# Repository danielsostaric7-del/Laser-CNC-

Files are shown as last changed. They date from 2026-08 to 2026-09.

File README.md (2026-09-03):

# 100 mm XY Laser CNC

I designed and built this small laser CNC engraver around two 100 mm linear stages and a LaserTree 5 W module. The frame, laser-height adjustment, and electronics enclosure were modeled in SOLIDWORKS. A Wemos D1 R32 running FluidNC controls the two axis through a CNC Shield V3 and DRV8825 drivers.

<p align="center">
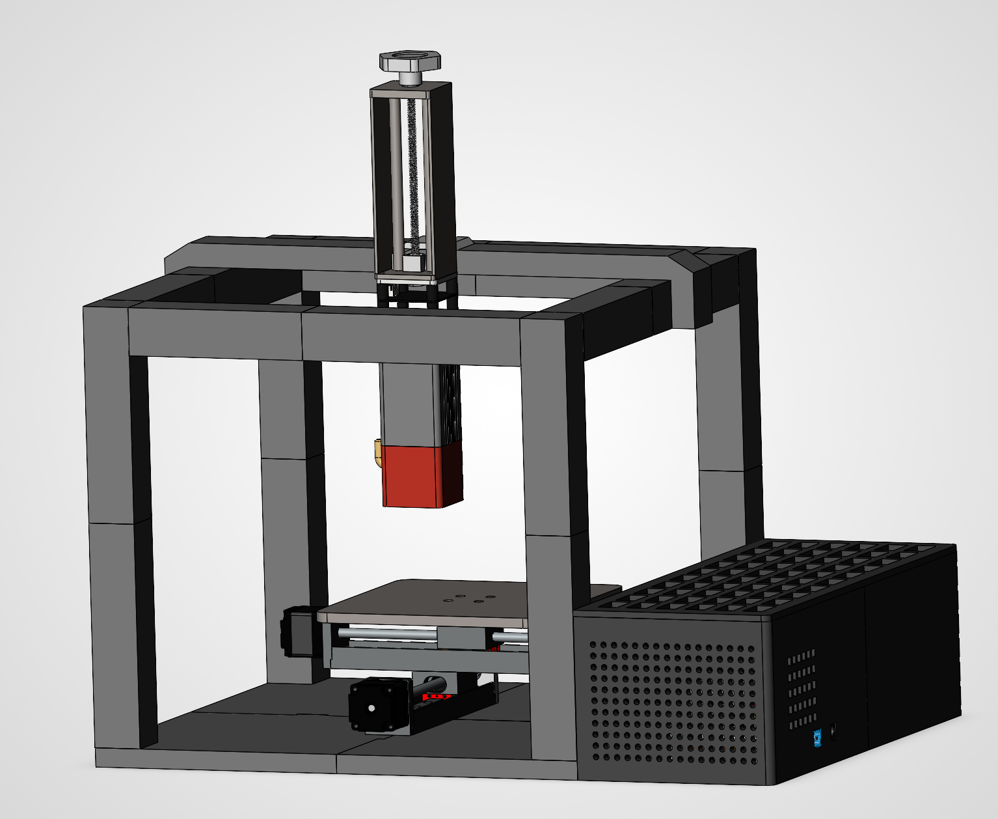
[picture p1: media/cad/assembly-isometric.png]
Full CNC assembly — my SOLIDWORKS isometric screenshot
  
</p>

[See all five SOLIDWORKS views](docs/cad-gallery.md)

## The finished machine

| Front | Electronics Box |
| --- | --- |
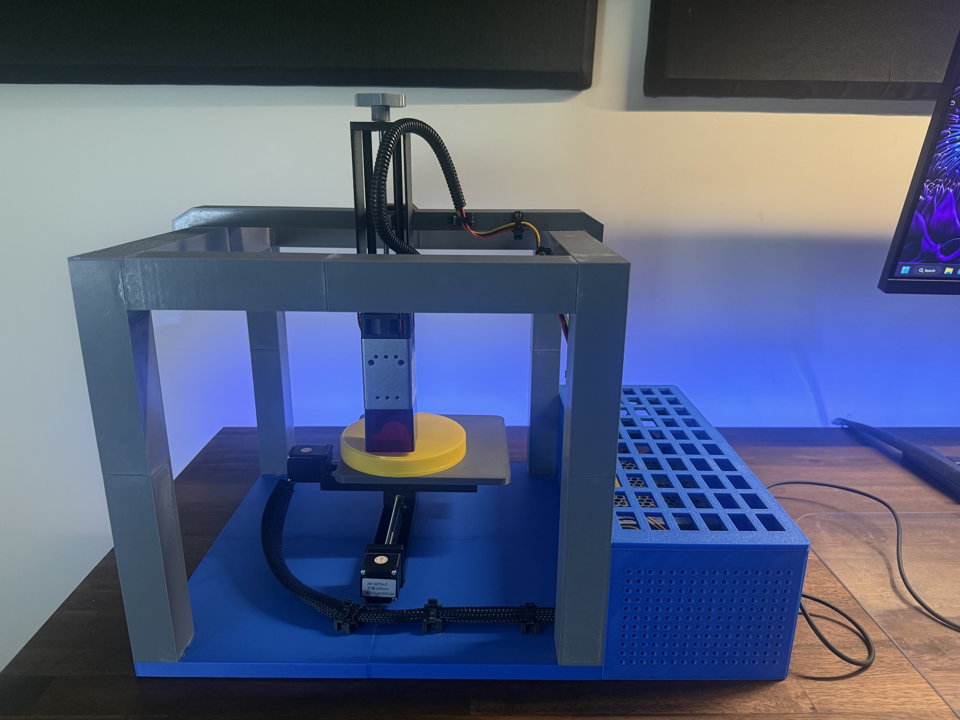
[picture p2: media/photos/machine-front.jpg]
Front of the finished CNC
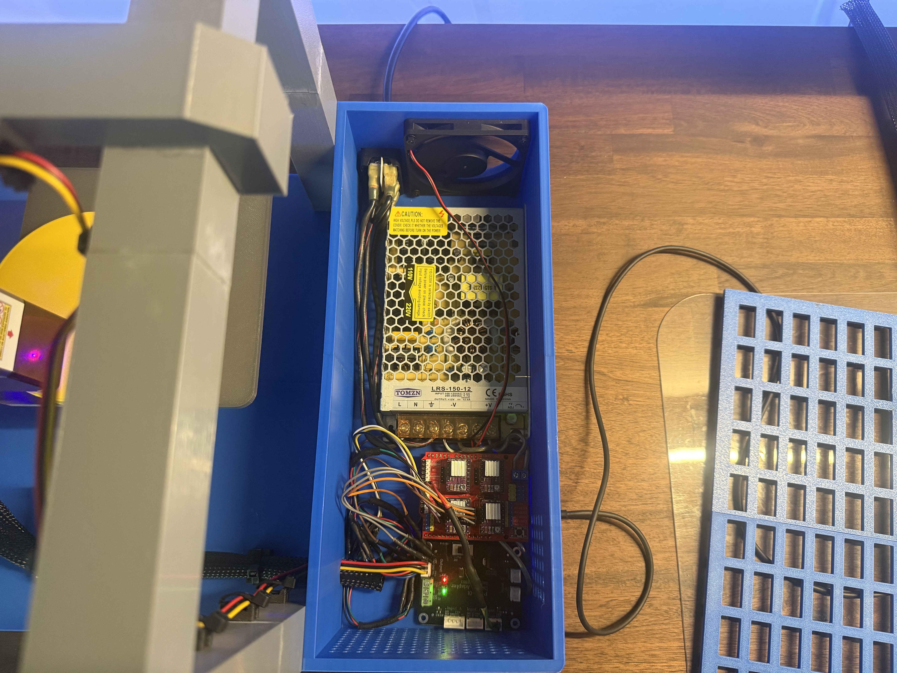
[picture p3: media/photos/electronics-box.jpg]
Electronics box of the finished CNC
|  |  |

[See all six photos](docs/photos.md), including the laser mount, electronics, power inlet, and test piece.

[Download the video](https://github.com/danielsostaric7-del/100mm-xy-laser-cnc/raw/refs/heads/main/media/video/assembly-overview.mp4) · [Video notes](docs/video.md)

## Setup

- 100 mm travel on each axis
- 3,200 steps/mm with 1/32 microstepping
- 600 mm/min configured maximum travel rate
- FluidNC v4 on a Wemos D1 R32
- 5 kHz laser PWM on GPIO19

The full pinout and motion settings are in [config.yaml](firmware/config.yaml).

## Circuit diagram

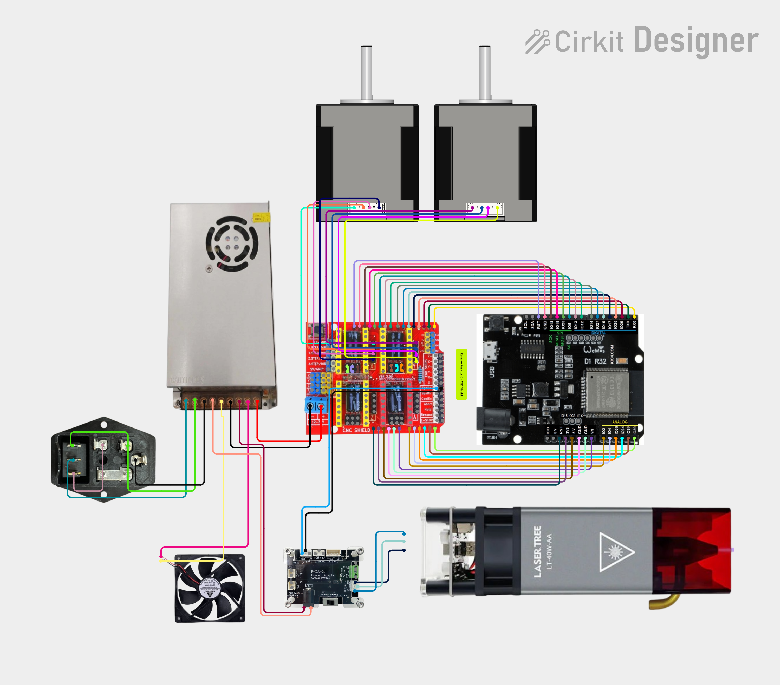
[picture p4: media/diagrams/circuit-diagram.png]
CNC wiring and circuit diagram


Click the diagram to open it at full size.

## Project files

| File or folder | What's inside |
| --- | --- |
| [CNC Assembly.SLDASM](cad/CNC%20Assembly.SLDASM) | The complete machine assembly |
| [CAD folder](cad/) | SOLIDWORKS parts and subassemblies |
| [FluidNC configuration](firmware/config.yaml) | Pin assignments and machine settings |
| [Circuit diagram](docs/circuit-diagram.md) | Wiring layout |
| [Bill of Material](docs/BOM.md) | Main parts and purchase links |

Keep the CAD folders together when opening the main assembly so SOLIDWORKS can find the referenced parts.

## Safety

This machine uses a high-power laser and electricity. The open frame shown here is not a laser-safe enclosure. Use a suitable enclosure, emergency stop, ventilation, and laser eyewear rated for the wavelength. Check grounding, polarity, driver current limits, and the laser's off-state before running it. Never leave it operating unattended.

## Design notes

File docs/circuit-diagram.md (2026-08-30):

# Circuit diagram

The wiring layout for the CNC controller, motors, laser, and power supply.

CNC wiring and circuit diagram

Click the diagram to open it at full size. Pin assignments and machine settings are in the [FluidNC configuration](../firmware/config.yaml).

[Bill of Material](BOM.md) · [Back to the project](../README.md)

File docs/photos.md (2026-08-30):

# Photos

The finished machine, a closer look at the hardware, and a test piece.

| Front | Side |
| --- | --- |
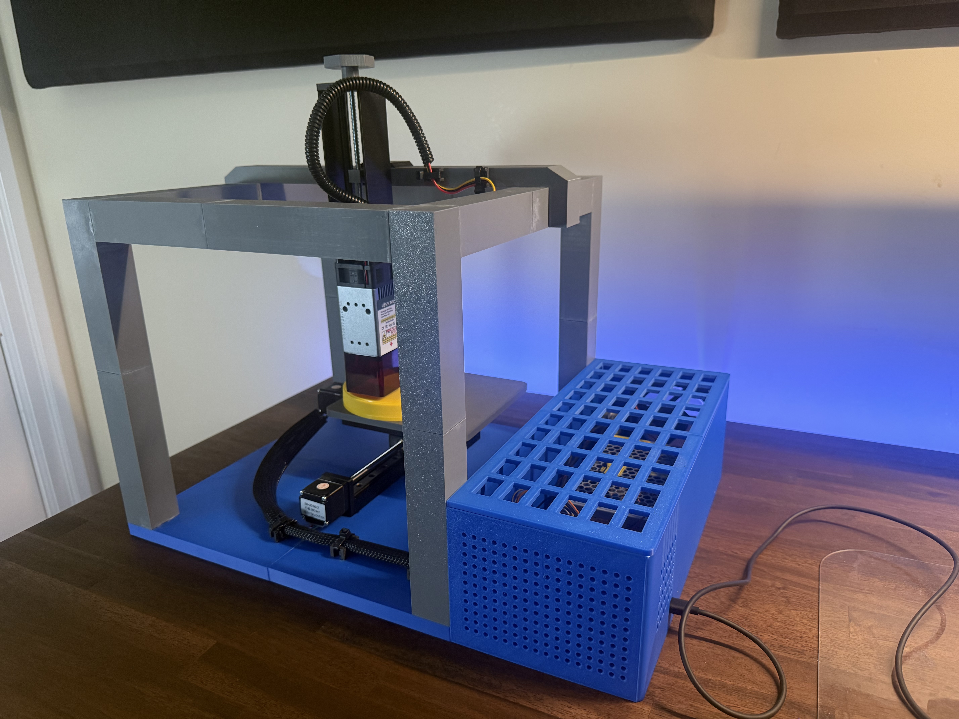
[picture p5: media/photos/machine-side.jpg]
Side of the completed CNC
| Front of the completed CNC |  |

| Laser mount and height adjustment | Inside the electronics enclosure |
| --- | --- |
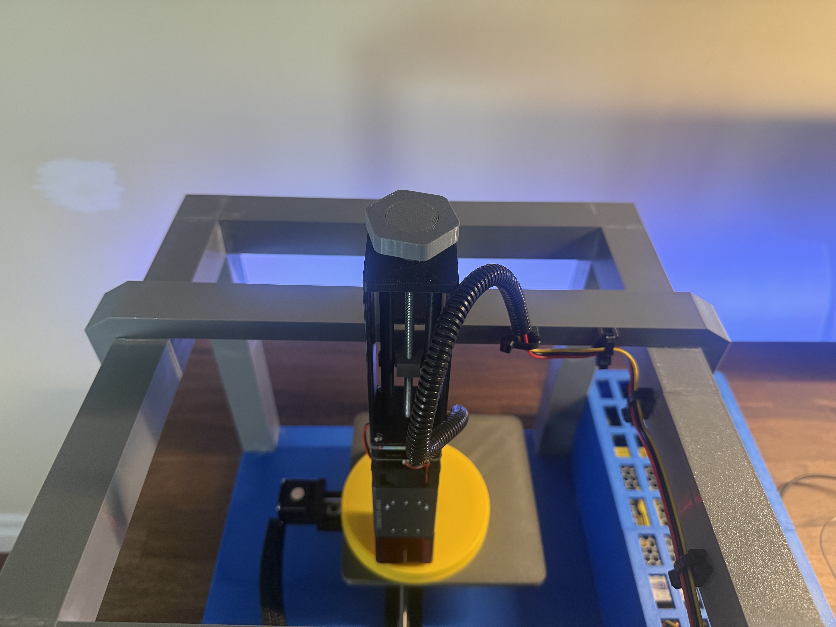
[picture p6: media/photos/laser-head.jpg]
Laser mount and height adjustment
|  | Power supply, controller, and wiring |

| Power inlet and cooling fan | Test piece |
| --- | --- |
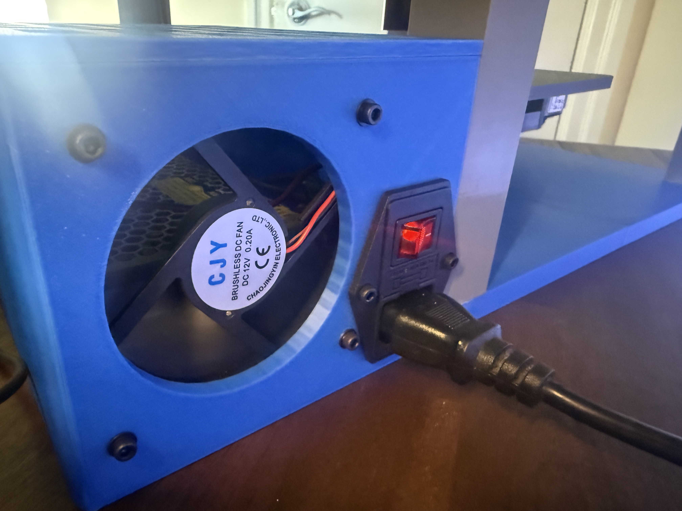
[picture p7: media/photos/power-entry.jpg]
Power inlet, switch, and fan
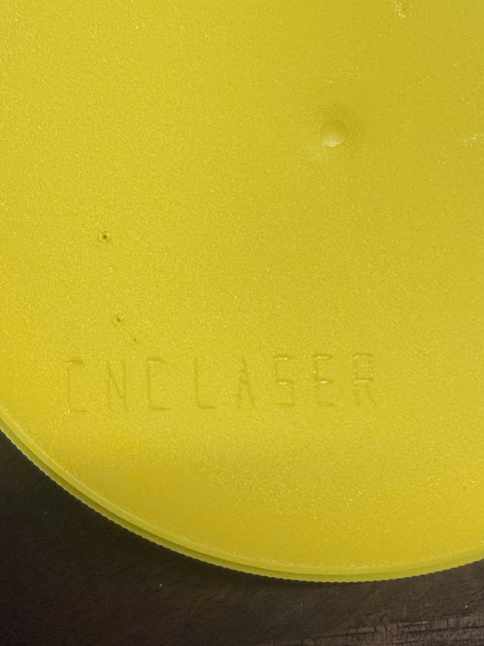
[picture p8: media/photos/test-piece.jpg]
Close-up of the test piece
|  |  |

Click a photo to view it at full size.

[SOLIDWORKS screenshots](cad-gallery.md) · [Circuit diagram](circuit-diagram.md) · [Back to the project](../README.md)

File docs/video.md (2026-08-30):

# Video

A short clip of the CNC.

[Download assembly-overview.mp4](https://github.com/danielsostaric7-del/100mm-xy-laser-cnc/raw/refs/heads/main/media/video/assembly-overview.mp4)

Use this download link instead of GitHub's file preview, which may say the video is too large to display. Open the downloaded MP4 in your video player. 

[Photos](photos.md) · [SOLIDWORKS screenshots](cad-gallery.md) · [Back to the project](../README.md)

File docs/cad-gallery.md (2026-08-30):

# SOLIDWORKS screenshots

Five views of the full CNC assembly, captured directly in SOLIDWORKS.

## Isometric

Full CNC assembly, isometric view

| Front | Side |
| --- | --- |
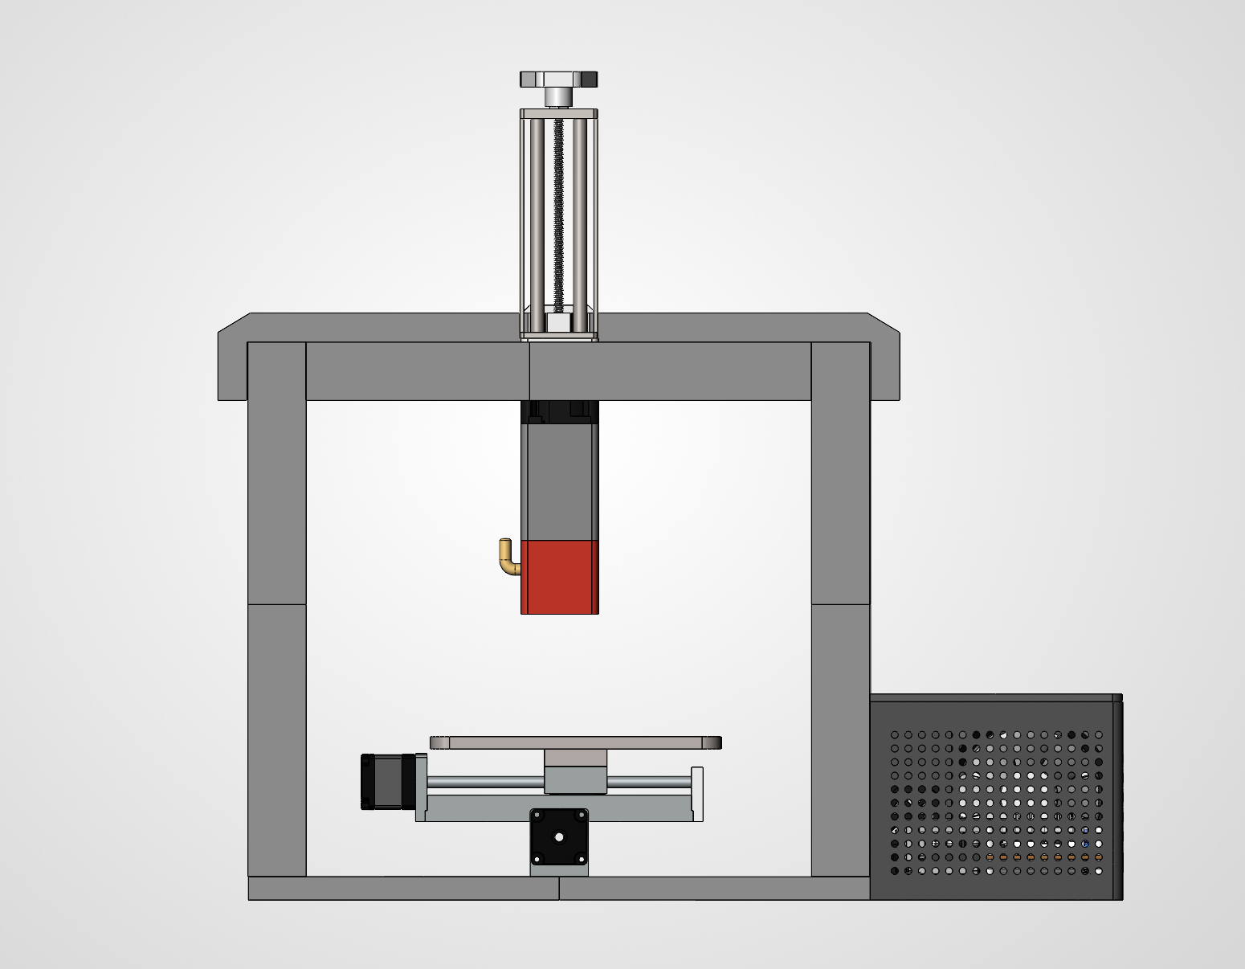
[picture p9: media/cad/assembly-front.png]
Front view
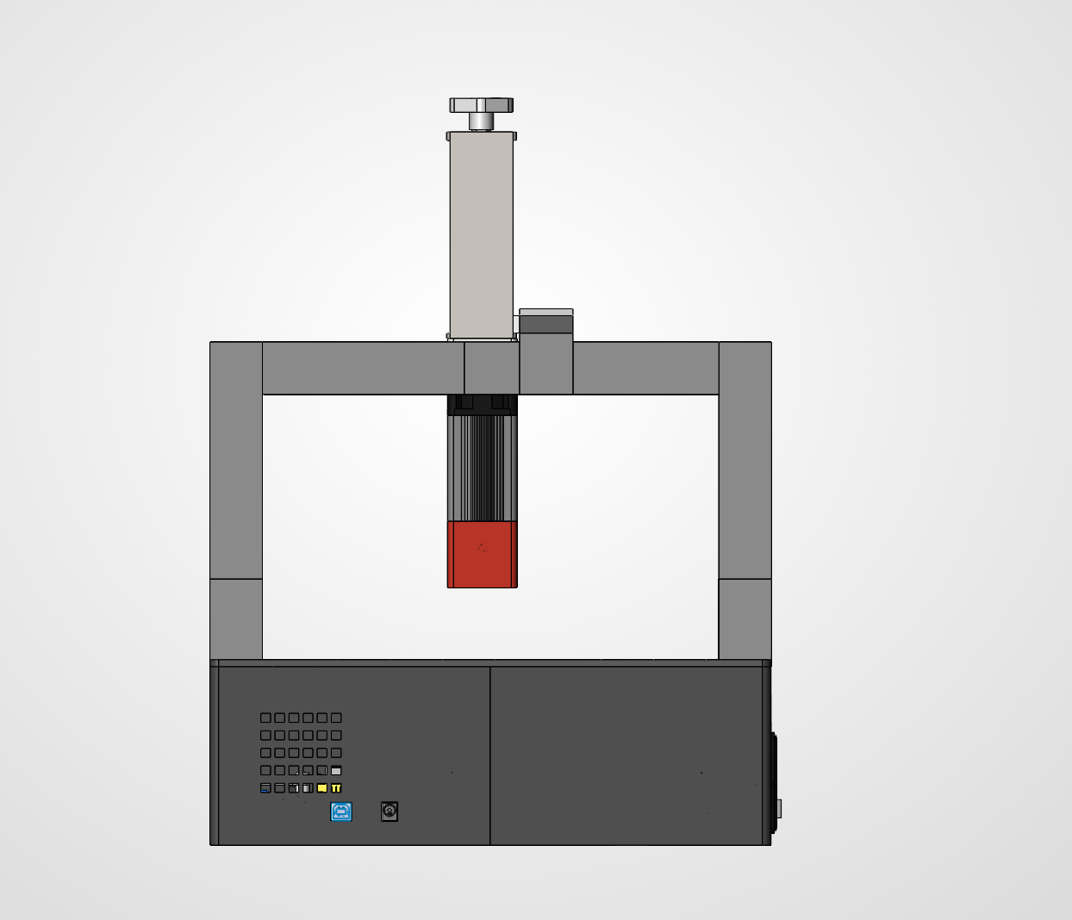
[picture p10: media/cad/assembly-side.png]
Side view
|  |  |

| Back | Top |
| --- | --- |
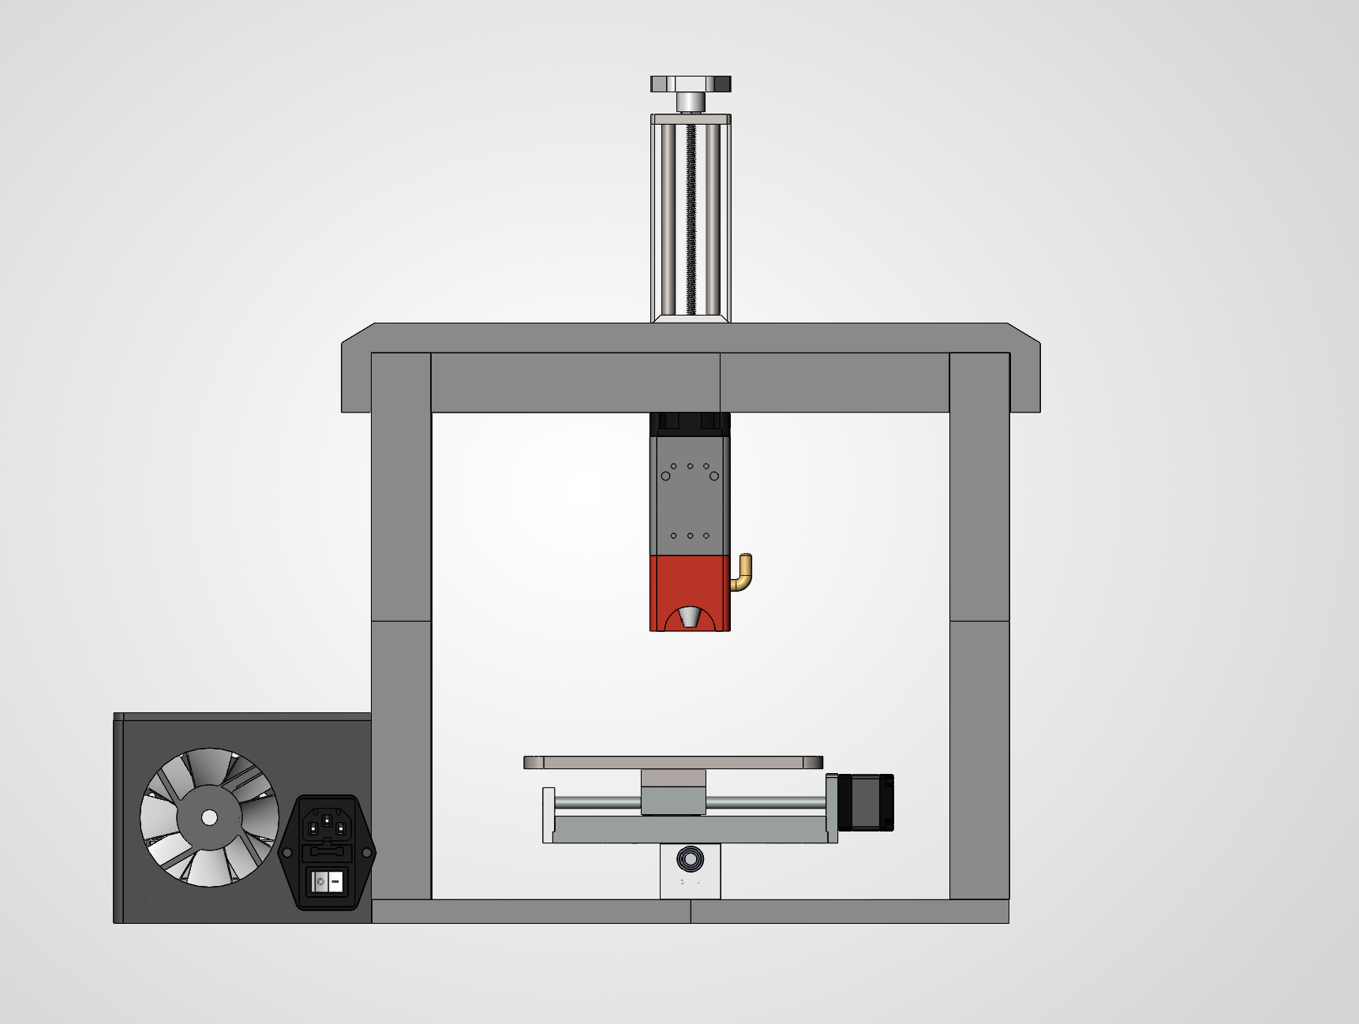
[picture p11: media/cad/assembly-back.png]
Back view
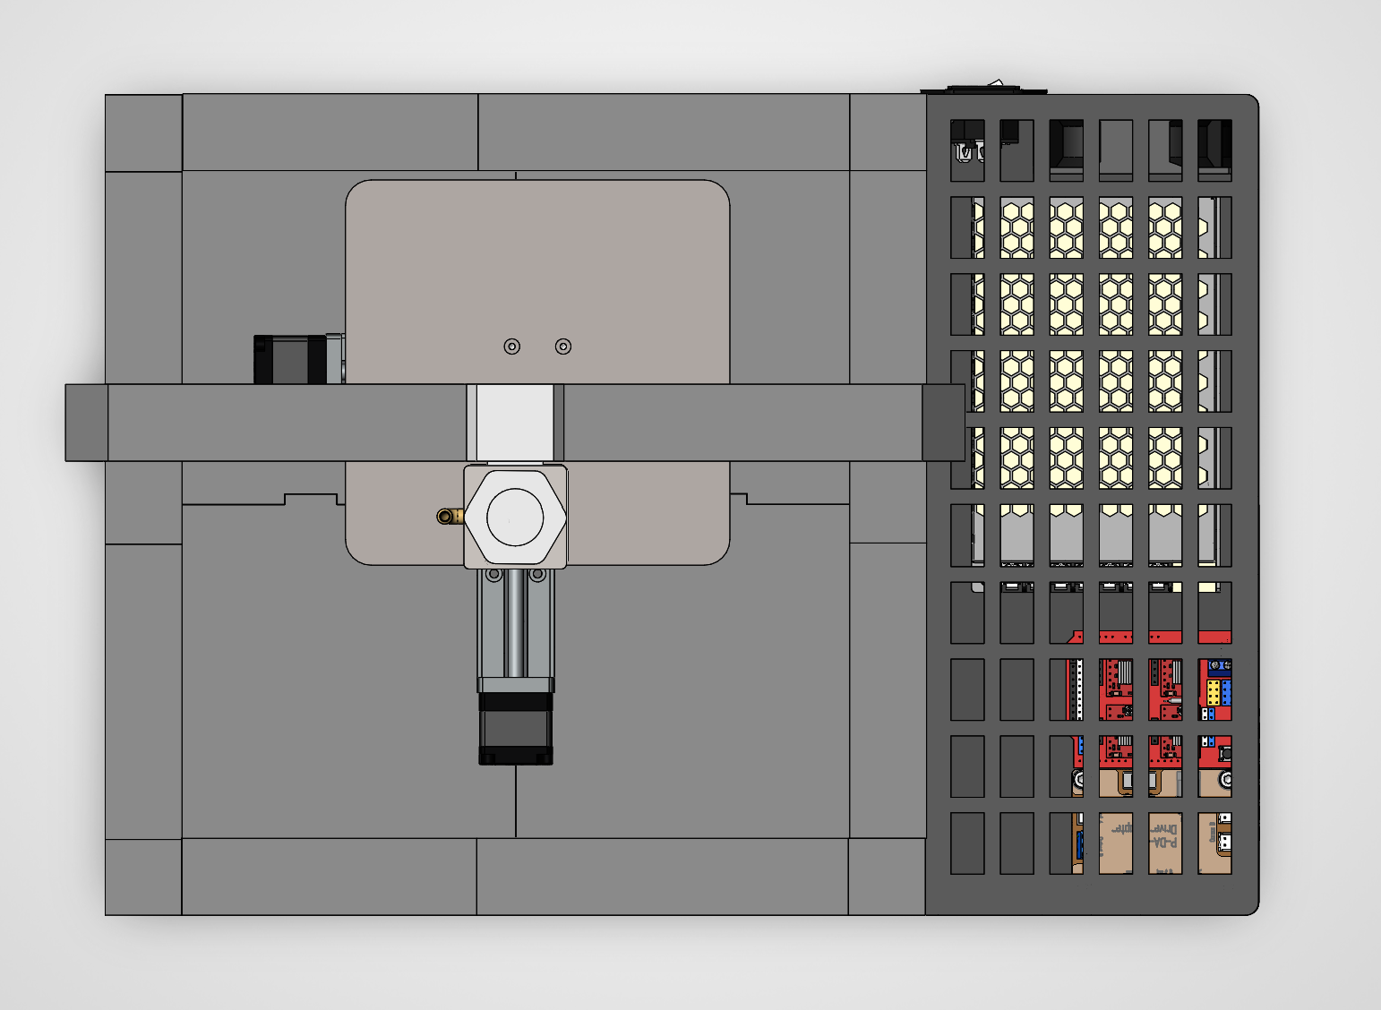
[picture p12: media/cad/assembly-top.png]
Top view
|  |  |

Click a screenshot to view it at full size.

[Open the assembly file](../cad/CNC%20Assembly.SLDASM) · [See the finished machine](photos.md) · [Back to the project](../README.md)

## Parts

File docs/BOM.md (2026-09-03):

# Bill of Material

The main parts used in this build.

| Part | Quantity |
| --- | ---: |
| Wemos D1 R32 | 1 |
| CNC Shield V3 | 1 |
| DRV8825 stepper driver | 2 |
| NEMA 11 linear stage, 100 mm travel | 2 |
| LaserTree LT-40W-A laser module, 5 W optical output | 1 |
| P-DA-01 laser driver adapter | 1 |
| LRS-150-12 power supply, 12 V / 150 W | 1 |
| IEC320-C14 inlet and switch | 1 |
| 12 V cooling fan | 1 |
| Custom frame, laser mount, and electronics enclosure | 1 set |

## Purchase links

These are the AliExpress listings from my orders. Check the selected size and version before ordering; some pages offer several options.

| Part | Link |
| --- | --- |
| Wemos D1 R32 | [AliExpress](https://www.aliexpress.com/item/32910354223.html) |
| Cooling fan | [AliExpress](https://www.aliexpress.com/item/1005007144892529.html) |
| CNC Shield V3 and stepper drivers | [AliExpress](https://www.aliexpress.com/item/1005006478108991.html) |
| LaserTree laser module | [AliExpress](https://www.aliexpress.com/item/1005006031010342.html) |
| Electrical Power Socket | [AliExpress](https://www.aliexpress.com/item/1005003012523694.html) |
| Linear Rail Motor | [AliExpress](https://www.aliexpress.com/item/1005008513205849.html) |
| Power supply | [AliExpress](https://www.aliexpress.com/item/1005008638665400.html) |

[Circuit diagram](circuit-diagram.md) · [Back to the project](../README.md)

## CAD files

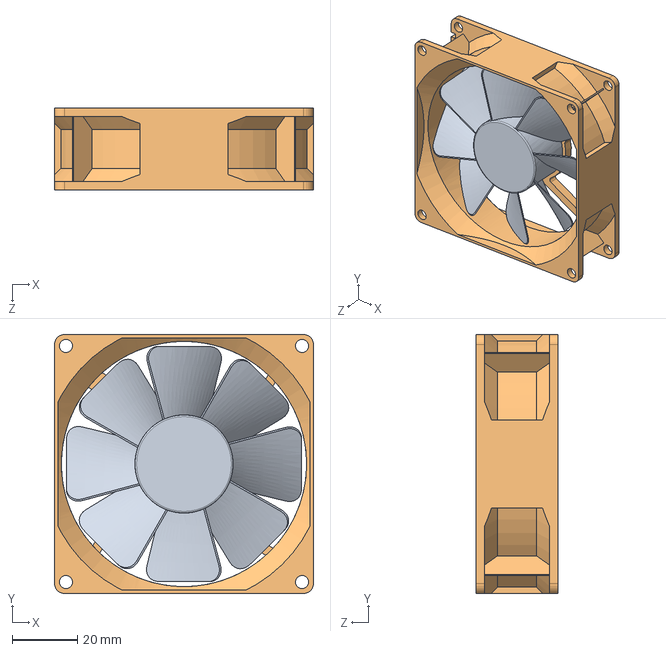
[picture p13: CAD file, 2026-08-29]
cad/Fan/cooler.SLDASM
79.2 x 79.2 x 25.0 mm

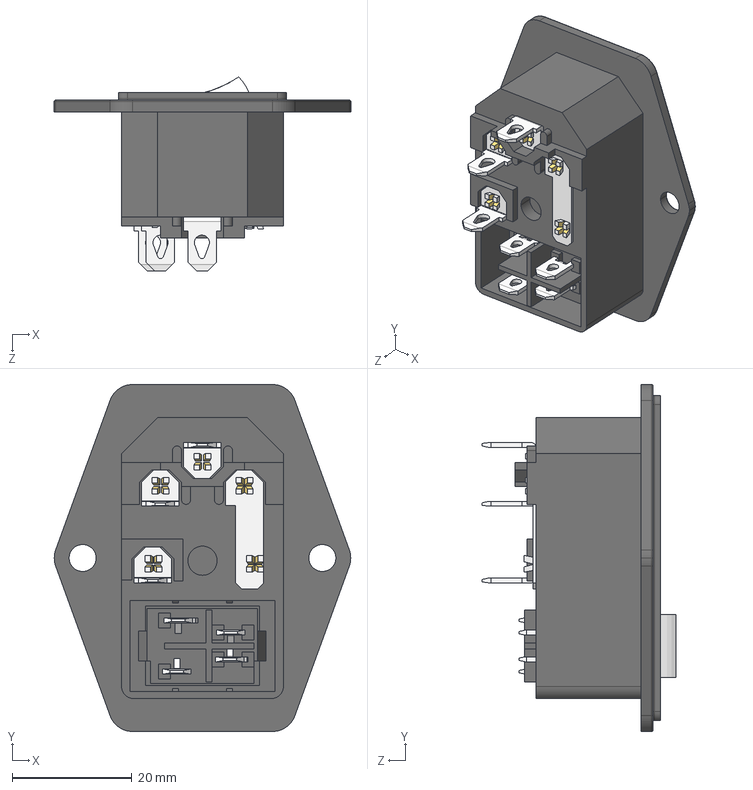
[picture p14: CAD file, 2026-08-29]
cad/AC Plug/IEC320-C14.STEP
49.5 x 57.9 x 32.4 mm
ilpm_case
fuse_clip_set
blade_15
blade_12 x 2
fuse-holder
fuse
switch_base
rocker
sm_tab_type1a
sm_tab_type1b
sm_tab_type2a
sm_tab_type2b
spot x 2
stamped_cond
correct_big_tab x 3

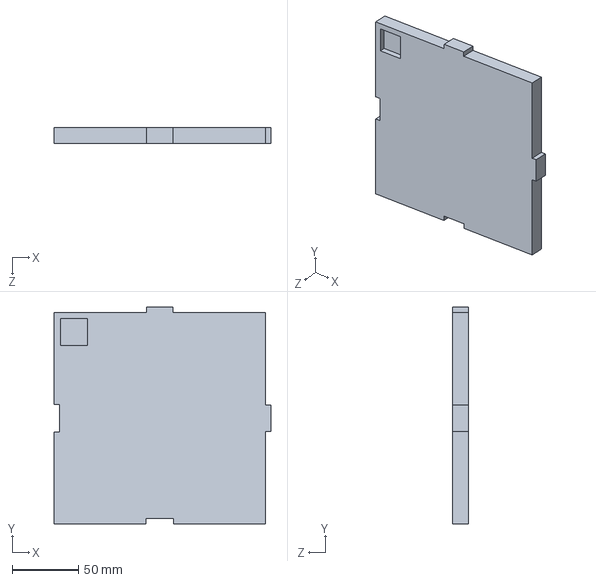
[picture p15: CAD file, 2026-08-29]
cad/Cage/CNC_Cage_Base_UL.SLDPRT
164.0 x 164.0 x 12.0 mm

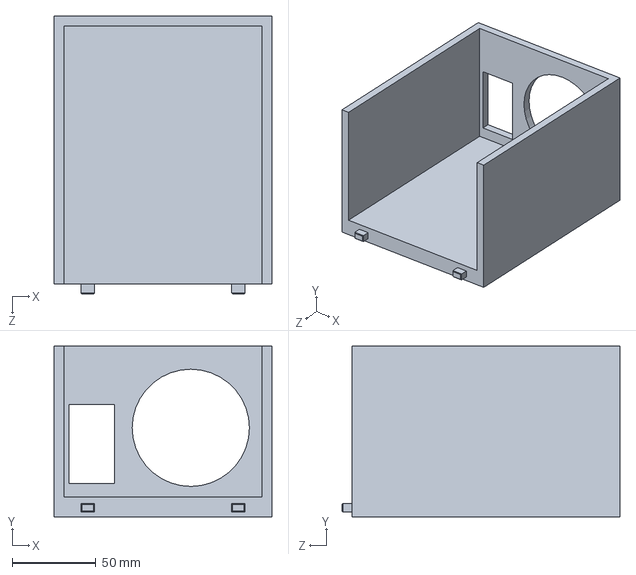
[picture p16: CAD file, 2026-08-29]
cad/Electronics Box/Box 1.SLDPRT
130.0 x 102.0 x 166.0 mm

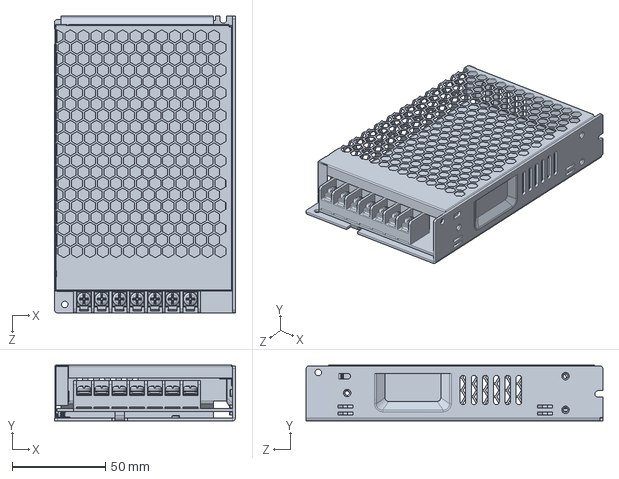
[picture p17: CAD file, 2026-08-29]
cad/Power Supply/LRS-150.SLDPRT
97.0 x 30.0 x 159.0 mm

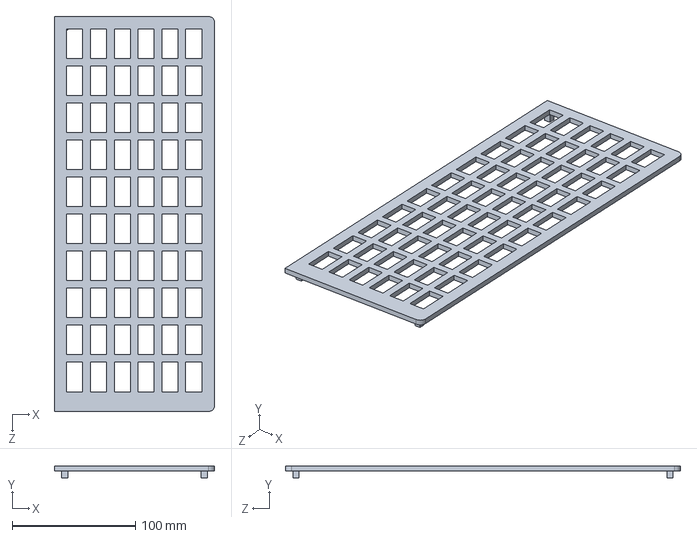
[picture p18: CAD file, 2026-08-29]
cad/Electronics Box/Grill.SLDPRT
130.0 x 10.0 x 320.0 mm

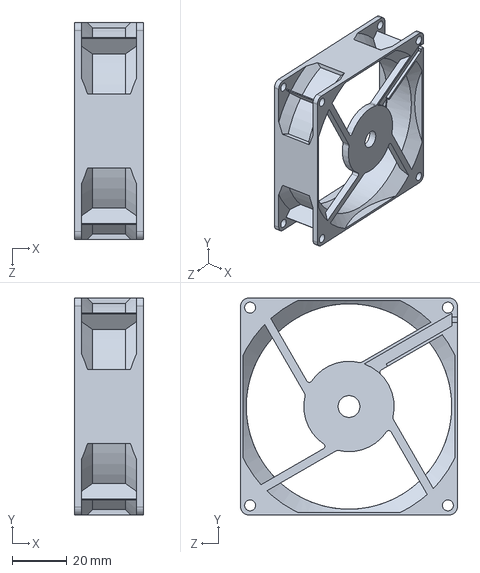
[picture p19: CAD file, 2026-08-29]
cad/Fan/Part2.SLDPRT
25.0 x 79.2 x 79.2 mm

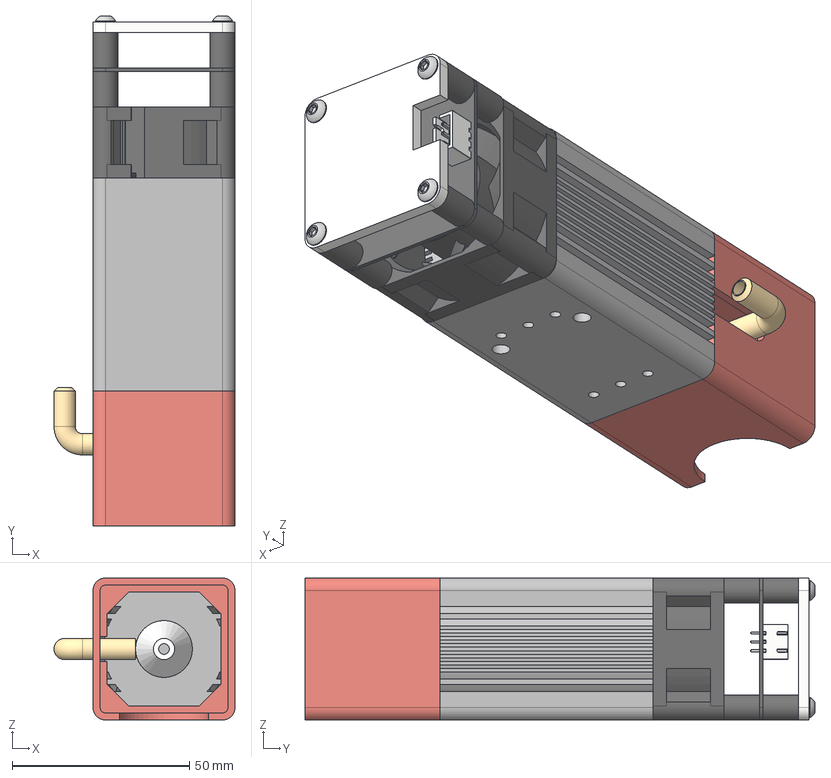
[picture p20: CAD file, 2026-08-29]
cad/Laser Tree Slider/Laser Tree 40W AA.step
51.0 x 143.7 x 40.0 mm
Blæser 40x20mm
Glas
Printplade
Afstand x 8
Laser Blok
Beskyttelse
Laser tud
Laser spids
Luft tud
M3x12mm x 4
JST-XH-3A_Scalable

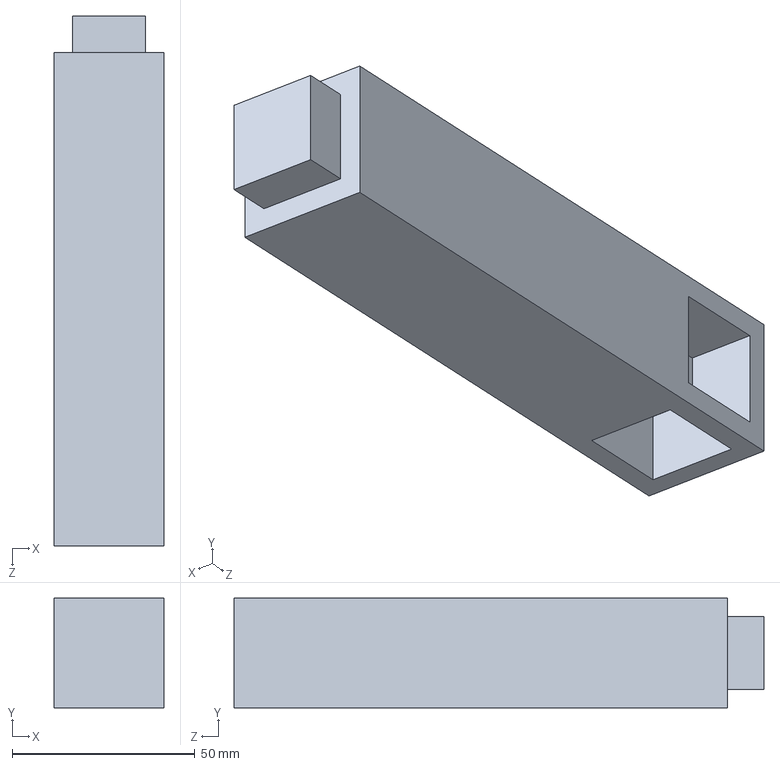
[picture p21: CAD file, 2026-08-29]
cad/Cage/CNC_Cage_Post_Upper.SLDPRT
30.0 x 30.0 x 145.0 mm

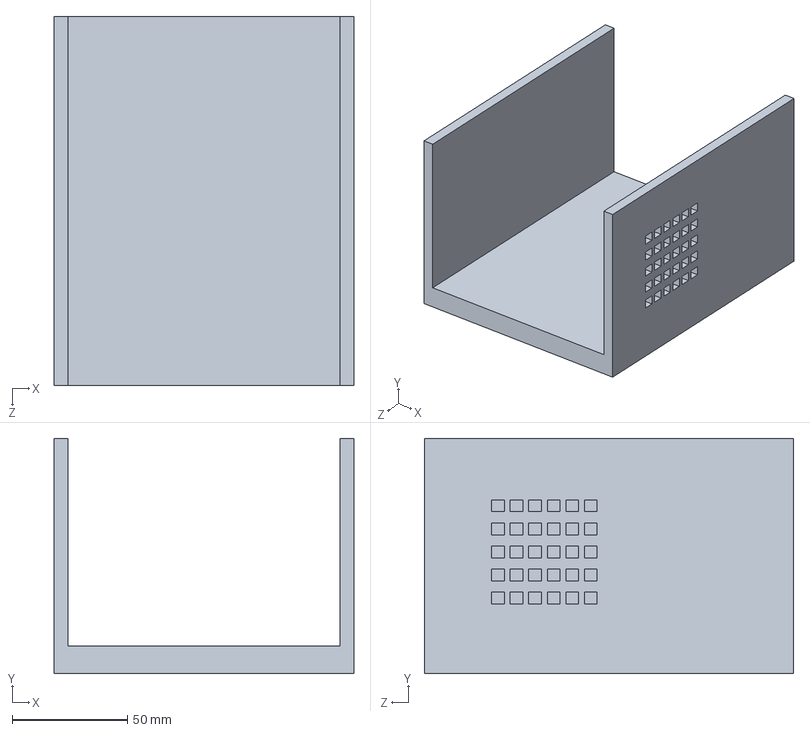
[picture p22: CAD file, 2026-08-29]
cad/Electronics Box/Box 2.SLDPRT
130.0 x 102.0 x 160.0 mm

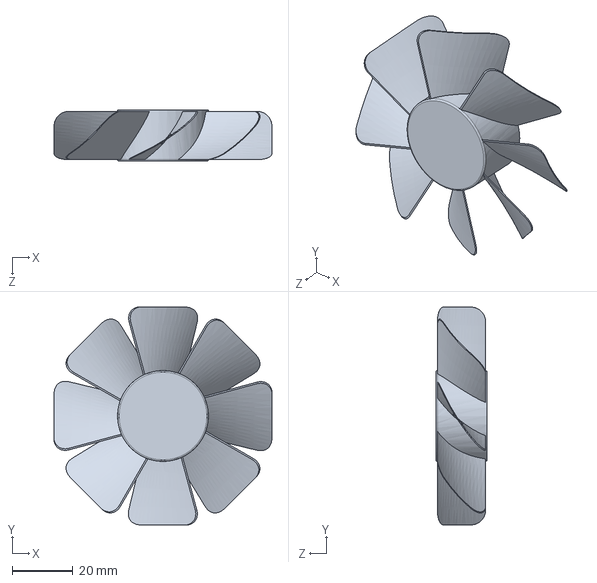
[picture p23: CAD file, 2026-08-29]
cad/Fan/part1.SLDPRT
72.0 x 72.0 x 17.0 mm

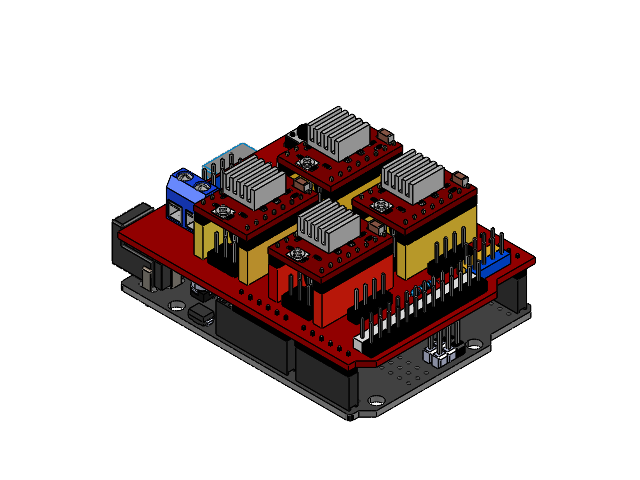
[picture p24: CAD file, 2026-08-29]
cad/CNC Shield/Arduino_CNC_Assembly.SLDASM
PCB.stp.STEP
USB-B.stp.STEP
DC_Jack.stp.STEP
Header female 8.stp.STEP
Header female 10.stp.STEP
Header female 8 (2).stp.STEP
Header female 6.stp.STEP
Header male 2.stp.STEP
Header male 2 (2).stp.STEP
Header male 2 (3).stp.STEP
Atmega328p-AU.stp.STEP
Diode.stp.STEP
LM358.stp.STEP
16MHZ Crystal.stp.STEP
16MHZ Crystal (2).stp.STEP
0603 Package.stp.STEP
0603 Package (2).stp.STEP
0603 Package (3).stp.STEP
0603 Package (4).stp.STEP
0603 Package (5).stp.STEP
0603 Package (6).stp.STEP
0603 Package (7).stp.STEP
0603 Package (8).stp.STEP
R1.stp.STEP
0603 Package (24).stp.STEP
0603 Package (23).stp.STEP
0603 Package (22).stp.STEP
0603 Package (21).stp.STEP
0603 Package (20).stp.STEP
0603 Package (19).stp.STEP
0603 Package (18).stp.STEP
0603 Package (17).stp.STEP
0603 Package (16).stp.STEP
0603 Package (15).stp.STEP
0603 Package (14).stp.STEP
0603 Package (13).stp.STEP
0603 Package (12).stp.STEP
0603 Package (11).stp.STEP
0603 Package (10).stp.STEP
0603 Package (9).stp.STEP
CH340G.stp.STEP
47uF 27v cap.stp.STEP
47uF 27v cap (2).stp.STEP
LM1117.stp.STEP
Transistor SOC Package.stp.STEP
Transistor SOC Package (2).stp.STEP
A sexy yellow button.stp.STEP
Arduino_Uno_CNC_Shield_V3.STEP

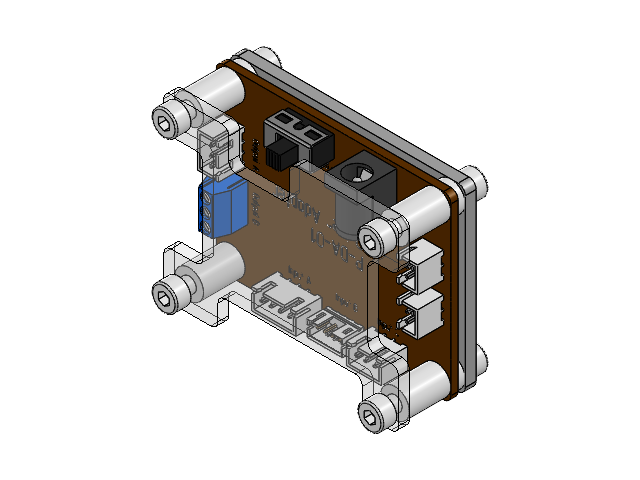
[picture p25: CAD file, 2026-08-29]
cad/P-DA-01/P-DA-01 Driver Adapter for LASER TREE K20 Pro.SLDASM
Plastic_Body_1of2.stp
Plastic_Body_2of2.stp
PIN_01.stp
PIN_03.stp
PIN_02.stp
Boner.stp
JST-B4B-PH-K-S.stp
DG350-3.5-03P-12-00AH.stp
eBom-prt8.stp
JST - XH - Thru - 4Pin - 2.54mm.stp
JST - XH - Thru - 3Pin - 2.54mm.stp x 2
JST - XH - Thru - 2Pin - 2.54mm.stp x 2
DIN912 - М4 x 10-03.stp x 8
eBom-FreeParts.stp

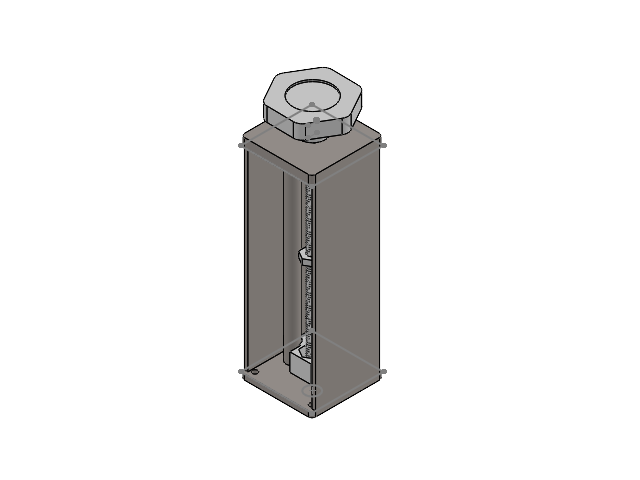
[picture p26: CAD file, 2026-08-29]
cad/Laser Tree Slider/Slider Assembly.SLDASM
LaserTree_Cage_Moving_140mm
Slider
Nut12 x 5
Knob
#10-24 X 0.750 SHCS_repaired

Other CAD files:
cad/Cage/CNC_Cage_Assembly.SLDASM
cad/Laser Tree Slider/Nut12.SLDPRT
cad/Cage/CNC_Cage_Base_UR.SLDPRT
cad/Actuator/Carriage.SLDPRT
cad/Actuator/00144585.SLDASM
cad/Actuator/00144585_01.SLDPRT
cad/Actuator/00144585_02.SLDPRT
cad/Actuator/00144585_03.SLDPRT
cad/Actuator/00144585_04.SLDPRT
cad/Actuator/00144585_05.SLDPRT
cad/Actuator/00144585_06.SLDPRT
cad/Actuator/00144585_07.SLDPRT
cad/Actuator/00144585_08.SLDPRT
cad/Actuator/00144585_09.SLDPRT
cad/Actuator/00144585_10.SLDPRT
cad/Actuator/00144585_11.SLDPRT
cad/Actuator/00144585_12.SLDPRT
cad/Actuator/00144585_13.SLDPRT
cad/Actuator/00144585_14.SLDPRT
cad/Actuator/Actuator_MGN9.SLDPRT
cad/Actuator/Actuator_MGN9C.SLDPRT
cad/Actuator/Base.SLDPRT
cad/Actuator/Bed.SLDPRT
cad/Actuator/LaserCage_Base_306mm_0p35.SLDPRT
cad/Actuator/Nema11.SLDPRT
cad/Actuator/Wall_Back.SLDPRT
cad/Actuator/Wall_Front.SLDPRT
cad/Cage/CNC_Cage_Base_LL.SLDPRT
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

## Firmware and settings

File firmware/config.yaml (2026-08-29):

# FluidNC v4 configuration
# Wemos D1 R32 + CNC Shield V3 + two DRV8825 drivers
# X/Y: 1.8-degree NEMA 11 linear stages, 2 mm lead, 100 mm travel
# DRV8825: M0/M1/M2 jumpers all installed (1/32 microstepping)
# Laser: LaserTree 5 W optical module, PWM connected to shield SpnEn

name: "100mm XY Laser"
board: "Wemos D1 R32 + CNC Shield V3"

verbose_errors: true
report_inches: false

stepping:
  engine: RMT
  idle_ms: 250
  pulse_us: 4
  dir_delay_us: 1
  disable_delay_us: 0

axes:
  # CNC Shield D8 / driver EN. If adding the shield causes a reset loop,
  # remove the shield and resolve its GPIO12 boot-strap/pull-up conflict first.
  # The CNC Shield EN line is active-low: GPIO12 LOW enables motion and
  # GPIO12 HIGH disables the drivers. This setting describes the DISABLE state.
  shared_stepper_disable_pin: gpio.12

  x:
    # 200 full steps/rev * 32 microsteps / 2 mm lead = 3200 steps/mm
    steps_per_mm: 3200.000
    max_rate_mm_per_min: 600.000
    acceleration_mm_per_sec2: 20.000
    max_travel_mm: 100.000
    soft_limits: false
    idle_disable: true
    motor0:
      limit_neg_pin: NO_PIN
      limit_pos_pin: NO_PIN
      limit_all_pin: NO_PIN
      hard_limits: false
      pulloff_mm: 1.000
      stepstick:
        step_pin: gpio.26
        direction_pin: gpio.16
        disable_pin: NO_PIN
    motor1:
      null_motor:

  y:
    # 200 full steps/rev * 32 microsteps / 2 mm lead = 3200 steps/mm
    steps_per_mm: 3200.000
    max_rate_mm_per_min: 600.000
    acceleration_mm_per_sec2: 20.000
    max_travel_mm: 100.000
    soft_limits: false
    idle_disable: true
    motor0:
      limit_neg_pin: NO_PIN
      limit_pos_pin: NO_PIN
      limit_all_pin: NO_PIN
      hard_limits: false
      pulloff_mm: 1.000
      stepstick:
        step_pin: gpio.25
        direction_pin: gpio.27
        disable_pin: NO_PIN
    motor1:
      null_motor:

  # FluidNC defines at least XYZ. This machine has no physical Z motor.
  z:
    steps_per_mm: 1.000
    max_rate_mm_per_min: 100.000
    acceleration_mm_per_sec2: 10.000
    max_travel_mm: 1.000
    soft_limits: false
    idle_disable: true
    motor0:
      null_motor:
    motor1:
      null_motor:

start:
  must_home: false

# Shield SpnEn is GPIO19 on the Wemos D1 R32 pin map.
# LaserTree LT-40W 5 W modules use TTL/PWM and a 5 kHz maximum PWM rate.
Laser:
  pwm_hz: 5000
  output_pin: gpio.19
  enable_pin: NO_PIN
  tool_num: 0
  speed_map: "0=0.000% 1000=100.000%"
  # This laser has no separate enable wire. Force PWM to zero for both
  # M5 and S0 so the beam cannot remain at the previous commanded power.
  s0_with_disable: true
  disable_with_s0: true
  off_on_alarm: true

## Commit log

2026-08-29 Add CNC project documentation, CAD, firmware, and media
    [#10-24 X 0.750 SHCS_repaired.SLDPRT, 00144585.SLDASM, 00144585_01.SLDPRT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]
2026-08-29 Add purchased AliExpress BOM links
2026-08-29 Use full CNC assembly as README hero
2026-08-29 Sync CAD files with updated project
    [Box 1.STL, Box 2.STL, CNC_Cage_Assembly.STEP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]
2026-08-30 Display circuit diagram in README
2026-08-30 Add circuit diagram docs and name verified purchase links
2026-08-30 Make circuit diagram a single docs page
